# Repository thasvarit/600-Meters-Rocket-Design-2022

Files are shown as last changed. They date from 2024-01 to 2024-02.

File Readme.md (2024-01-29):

# Rocket Optimization Project Overview

## Introduction

The [Thailand CANSANT-ROCKET Competition](https://www.facebook.com/p/CanSat-Rocket-Thailand-100038803825229/), organized by the National Science Museum (NSM) and the Defence Technology Institute (DTI), invites high school students to design and test CanSats and rockets. For the rocket part, students don't have to create their own rocket motor, with the total impulse of 255 Ns, as DTI has it covered.

This GitHub page displays our rocket project for Team Nuage, the winner of the Aerodynamics Award at the Thailand CANSAT-ROCKET Competition 2022. Thanks to Phachara Phumiprathet's guidance, we've set a more realistic goal within our time constraints. My role is to design the rocket for our team in this competition.

## Method

I started using rocket optimization feature of [OpenRocket](https://openrocket.info/) to increase its altitude by tweaking the nose cone's shape and length. Strangely, OpenRocket suggested a short, blunt nose cone. I was skeptical, but when I double-checked with [Aerolab](https://www.nakka-rocketry.net/softw.html#Aerolab), the results matched. It seemed strange, going against [what we knew about physics](https://aerospaceweb.org/question/aerodynamics/q0151.shtml).

Digging deeper, I found pressure drag was a big factor. So, I went with a [von Kármán-style nose cone](https://en.wikipedia.org/wiki/Nose_cone_design#Von_K%C3%A1rm%C3%A1n) of with the length of 12 cm to lower pressure drag without adding the weight that comes with a longer nose cone.

Wisit Wipudgasamsook also recommended striking the right balance between static margin and altitude, so I get a 2 cm tip chord length, influencing the design of the fins. Adhering to the competition's requirement of 4 fins, my design decisions were not only in compliance but also geared towards ensuring the rocket's balance and optimal performance.

Following my design process, Shinakrit Laokittichai proceeded to assemble the rocket components in preparation for launch.

## Outcome

During the presentation before the launch, the committees weren't sure about the simulation results showing an altitude of 652 m. They thought it was too high since the given rocket motor from DTI was supposed to reach a maximum of 600 m. I double-checked everything in my simulations but found no issues.

In the end, my rocket reached 577 meters, slightly off from the expected result by 12%. Still, it outperformed other teams, whose rockets had an average altitude of 391 meters with a standard deviation of 120. The result of all this work is that our rocket got the Best Aerodynamics Award from the Thailand CANSAT-ROCKET Competition 2022.

## Citation

[1] Thitasirivit, Vivatsathorn & Ngamdeevilaisak, Bhavat & Vongbunsin, Chayakorn. (2018). Agricultural Exploration Assistant Satellite: Thailand CanSat Competition 2018 Preliminary Proposal. DOI: [10.13140/RG.2.2.11933.38882](https://doi.org/10.13140/RG.2.2.11933.38882)

[2] M. Ostaszewski, K. Dzierzek, Ł. Magnuszewski (2018). "Analysis of data collected during CanSat mission." In 2018 19th International Carpathian Control Conference (ICCC), Szilvasvarad, Hungary, pp. 1-4. DOI: [10.1109/CarpathianCC.2018.8399591](https://doi.org/10.1109/CarpathianCC.2018.8399591)

[3] Abate, M. T., Anandapadmanaban, E., Bao, L., Challani, S., Gaughan, J., Jiang, A., ... Zorn, S. E. (2014). Correlation between simulated, calculated, and measured model rocket flight. Retrieved from https://www.semanticscholar.org/paper/CORRELATION-BETWEEN-SIMULATED-%2C-CALCULATED-%2C-AND-Abate-Anandapadmanaban/f1273cf8d5df09aa30bc7d80c9ef3b260b1a4f53

[4] Crowell, G. A. (n.d.). The Descriptive Geometry of Nose Cone. Retrieved from https://www.scribd.com/doc/60921375/the-descriptive-geometry-of-nosecone

The images provided were captured by Vivatsathorn Thitasirivit, Nattakit Kwankitpisarn, Thanyapisit Kangsathien, Arkkanirut Pandej, and were sourced from a Facebook post by Dr. Rattapol Sakornsin.

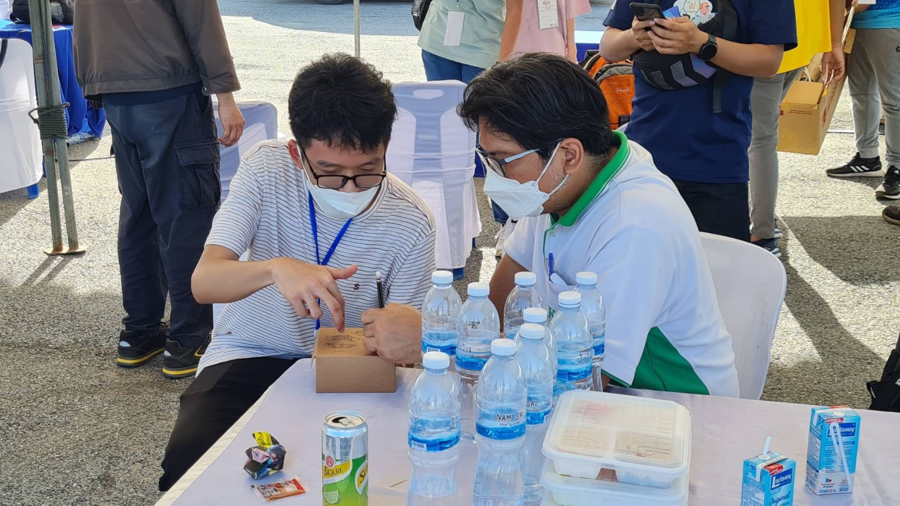
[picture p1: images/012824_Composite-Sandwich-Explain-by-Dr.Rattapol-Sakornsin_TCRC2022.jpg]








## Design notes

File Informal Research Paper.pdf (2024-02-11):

การออกแบบจรวดให้พิสัยการยิงมากที่สุดในช่วงความเร ็

วต่า กว่าเสียง ส าหรับ
รายการแข่งขัน Thailand CANSAT-ROCKET Competition 2022 ธรรศวริทธิ์เครือคลา้ย
ก

, ชินกฤต เหล่ากิตติชัยก

, วิศิษฎ์ วิพัฒน์เกษมสุขข

, พชร ภูมิประเทศก

ก

โรงเรียนอัสสัมชัญ
ขสถาบันเทคโนโลยีป้องกันประเทศ

ที่มาและความสำคัญ
ปัจจุบันการพัฒนาด้านวิศวกรรมการบิน และอวกาศของประเทศไทยยังคงอยู่ในช่วงเริ่มต้น โดยการยิง จรวดเพื่อการวิจัยทดสอบก่อนนำระบบไปใช้จริงนั้นเป็นหนึ่งในขั้นตอนสำคัญในการทำงาน ด้วยเหตุนี้จึงมีการ จัดการแข่งขัน Thailand CANSAT-ROCKET Competition 2022 ซึ่งเปิดโอกาสให้นักเรียนระดับมัธยมปลายได้ ออกแบบดาวเทียมจำลอง และจรวดเป็นของตนเอง โดยได้รับการสนับสนุนจากกระทรวงวิทยาศาสตร์ และ เทคโนโลยีแห่งชาติ (สวทช.) และสถาบันเทคโนโลยีป้องกันประเทศ (สทป.) การศึกษานี้จะศึกษาปัจจัยที่ส่งผลต่อ การออกแบบจรวดให้ลู่ลม เพื่อพิสัยการยิงสูงสุดของจรวด ภายใต้ข้อจำกัดของการแข่งขัน ข้อจำกัดในการออกแบบจรวด
รายการแข่งขัน Thailand CANSAT TOCKET Competition 2022 กำหนดให้ใช้ท่อจรวดที่มีเส้นผ่าน ศูนย์กลางนอก 80 mm โดยมีความหนา 2 mm และใช้มอเตอร์จรวดที่มีการดลรวม 255 mS ในการขับเคลื่อน

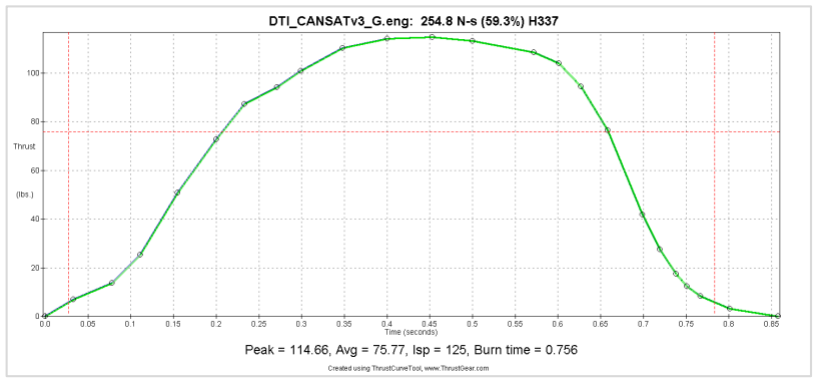
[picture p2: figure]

ภาพที่ 1: กราฟแรงขับของมอเตอร์จรวดจากโปรแกรม Thrust Curve Tool

ระเบียบวิธีการวิจัย

### 1. การออกแบบหัวจรวด ทำการทดลองทดสอบอิทธิพลจากการใช้หัวจรวดทุกประเภทที่สามารถ Simulation

ผ่านโปรแกรม OpenRocket ซึ่งได้แก่ LV-Haack, LD-Haack, 0.5 Parabola, 0.75 Parabola, Ellipsoid. Conical. Tangent Ogive และ Secant Ogive ที่ความยาวตั้งแต่ 1 – 30 cm ซึ่งรวมถึงช่วงความยาวใน อัตราส่วน 2 – 3 เท่าซึ่งเป็นช่วงที่เหมาะสมตามทฤษฎีการออกแบบหัวจรวด เมื่อเปรียบเทียบกับเส้นผ่าน ศูนย์กลางนอกของท้อจรวด โดยค่าที่พล็อตร่วมกับความยาวหัวจรวด คือข้อมูล Nose Cone Pressure Drag, Nose Cone Friction Drag และ Body Friction Drag ซึ่งนำเข้าข้อมูลจากแท็บ Drag Characteristic ของ หน้าต่าง Component Analysis จากโปรแกรม OpenRocket มาพล็อตเพื่อวิเคราะห์ในโปรแกรม Minitab

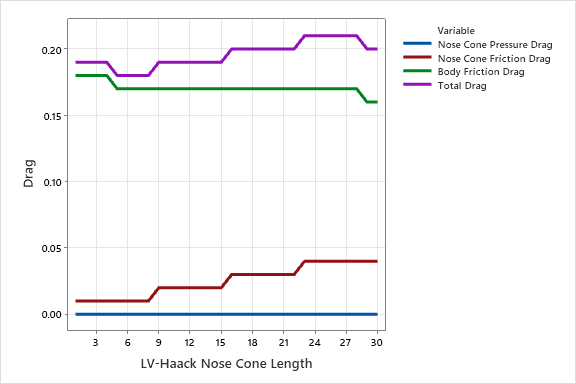
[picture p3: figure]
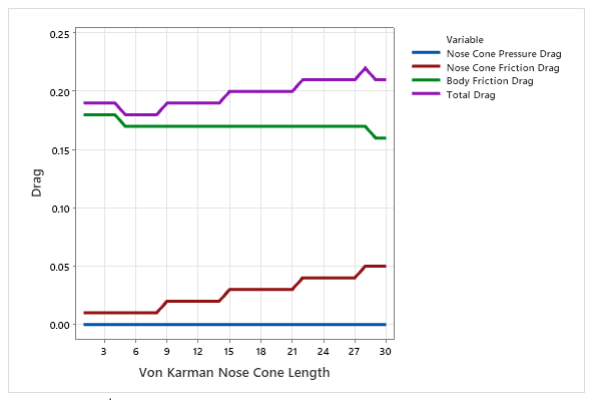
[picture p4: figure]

กราฟที่ 1: ความยาวหัวจรวด LV-Haack – แรงฉุด | กราฟที่ 2: ความยาวหัวจรวด Von Karman (LD-Haack) – แรงฉุด

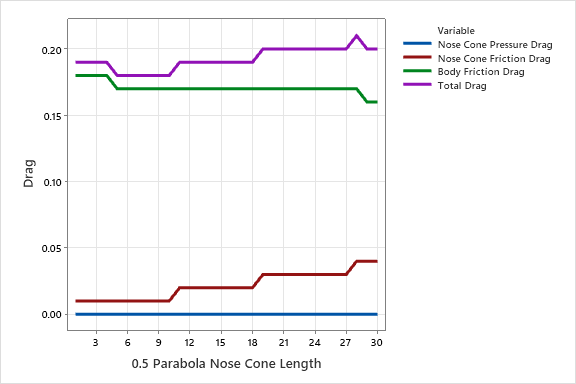
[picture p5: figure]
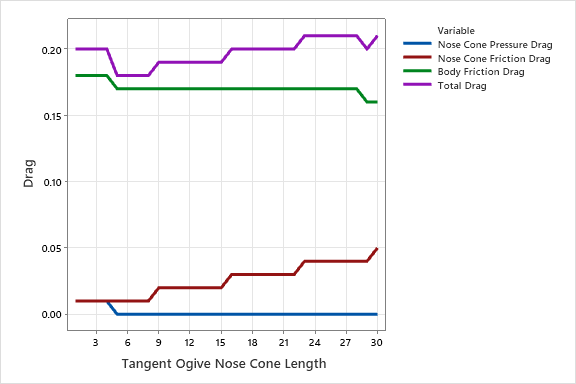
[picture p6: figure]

กราฟที่ 3: ความยาวหัวจรวด 0.5 Parabola – แรงฉุด | กราฟที่ 4: ความยาวหัวจรวด Tangent Ogive – แรงฉุด

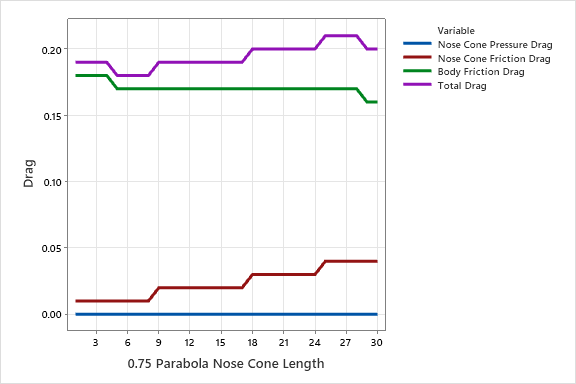
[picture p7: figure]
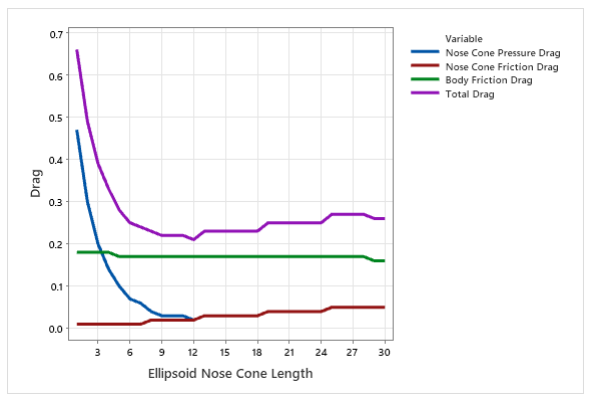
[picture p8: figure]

กราฟที่ 5: ความยาวหัวจรวด 0.75 Parabola – แรงฉุด | กราฟที่ 6: ความยาวหัวจรวด Ellipsoid – แรงฉุด

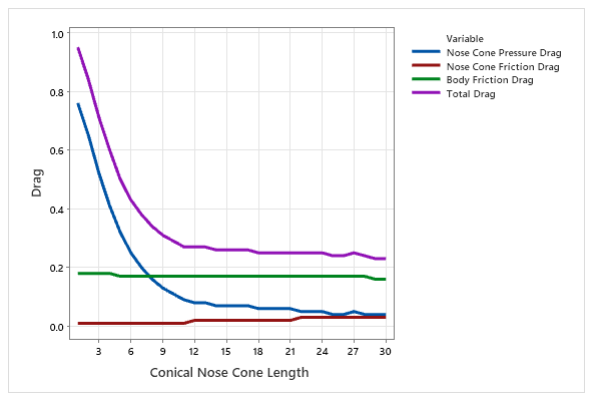
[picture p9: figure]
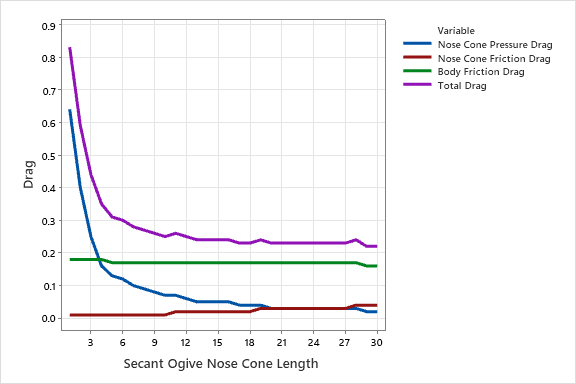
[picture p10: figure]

จะเห็นได้ว่าลักษณะของกราฟนั้นแบ่งออกเป็น 2 ประเภท ประเภทแรกคือกราฟที่มี แรงฉุดจากความดันต่อหัว จรวด (Nose Cone Pressure Drag) ใกล้เคียงกับ 0 คือกราฟที่ 1 – 5 ซึ่งได้แก่หัวจรวดทรง Von Karman, LV-Haack, 0.5 Parabola, Tangent Ogive และ 0.75 Parabola และประเภทที่ 2 คือกราฟที่ 6 – 8 คือประเภทที่มี แรงฉุดจากความดันต่อหัวจรวดต่ำลงตามความยาวของหัวจรวด ซึ่งตามทฤษฎีทางอากาศพลศาสตร์ แนวโน้มของ แรงฉุดความดันต่อหัวจรวดควรเป็นเหมือนกราฟประเภทที่ 2 คือแรงฉุดจากความดันจะมีค่ามากเมื่อหัวจรวดมี ลักษณะทู่ และต่ำลงเมื่อหัวมีลักษณะแหลมมากขึ้น ดังนั้นผู้ศึกษาจึงตั้งสมมติฐานเพื่อเลือกความยาวที่เหมาะสม ของหัวจรวดว่าแท้จริงแล้วแรงฉุดจากความดันของกราฟประเภทแรก ย่อมต้องเป็นไปในทิศทางเดียวกับกราฟ ประเภทที่ 2 และโดยภาพรวม ตัวแปรที่มีความผันแปรมากที่สุดตามความยาวของหัวจรวด คือแรงฉุดจากความดัน ต่อหัวจรวด โดยจากกราฟ อัตราการลดลงของแรงฉุดจากความดันต่อหัวจรวดจะลดลงเมื่อมีหัวจรวดมีความยาว มากขึ้น ความสูงของจรวดนั้นขึ้นอยู่กับ 2 ปัจจัยหลัก คือมวลของจรวด และแรงฉุดรวมต่อจรวด ซึ่งความยาวของ หัวจรวดส่งผลต่อทั้ง2 ปัจจัย ผู้ศึกษาจึงต้องหาจุดสมดุลระหว่างอิทธิพลของทั้ง 2 ปัจจัยเพื่อเลือกความยาวหัวจรวด ที่มีความเหมาะสมที่สุด แต่ด้วยข้อจำกัดด้านเวลา ผู้ศึกษาเลือกใช้หัวจรวดความยาว 12 เซนติเมตร ซึ่งเป็นความ ยาวที่ผู้ศึกษาเห็นว่าหลังจากพ้นค่านี้ไปแล้ว การเพิ่มความยาวของหัวจรวดจะลดปริมาณแรงฉุดเพียงเล็กน้อย สำหรับการคัดเลือกรูปร่างหัวจรวด ผู้ศึกษาใช้การคัดเลือกจากการทบทวนวรรณกรรม และใช้หัวจรวดทรง Von Karman ซึ่งเป็นทรงหัวจรวดที่ถูกออกแบบขึ้นมาเพื่อลดแรงฉุดโดยเฉพาะ โดยสมการเพื่อกำหนดรูปร่างของหัว จรวดทรง Von Karman คือ

y =

1
√π

√θ −
1
2

sin (2θ)

เมื่อ θ = cos⁻¹
(1 – 2x )

สมการที่ 1: เส้นโค้ง Von Karman

กราฟที่ 7: ความยาวหัวจรวด Conical – แรงฉุด | กราฟที่ 8: ความยาวหัวจรวด Secant Ogive – แรงฉุด

จึงนำสมการดังกล่าวไปเขียนโปรแกรมในโปรแกรม Matlab ดังภาพที่ 9 โดยกำหนดให้เส้นผ่านศูนย์กลางของหัว จรวดเท่ากับ 80 และความยาวหัวจรวดเท่ากับ 120 ซึ่งจากการเพิ่มค่าความยาวหัวจรวดในลูปของโปรแกรมแต่ละ ครั้ง ครั้งละ 0.1 ทำให้ได้พิกัดเพื่อสร้างเส้นโค้ง Von Karman ทั้งหมด 1200 พิกัด โดยได้ทำการพล็อตทดสอบดัง ภาพที่ 10 จากนั้นนำเข้าพิกัดเข้าสู้โปรแกรม SolidWorks ทำการ Offset 2 เซนติเมตร แล้ว Revolve รอบแกนให้ หัวจรวด Von Karman มีความหนา 2 เซนติเมตร จากนั้นสร้าง Shoulder โดยกำหนดให้มีเส้นผ่านศูนย์กลางนอก เล็กกว่าท่อจรวด 0.5 เซนติเมตร และมีความยาว 5 เซนติเมตร เพื่อให้สามารถเสียบหัวจรวดเข้ากับท่อจรวดได้พอดี

2.การออกแบบครีบจรวด เนื่องจากผู้ศึกษามีความสนใจในการออกแบบครีบจรวดแบบสี่เหลี่ยมคางหมู การศึกษา นี้จึงมุ่งศึกษาปัจจัยที่ส่งผลต่อความสูงของครีบจรวดแบบสี่เหลี่ยมคางหมูซึ่งตัวแปรที่สำคัญที่สุดในการออกแบบ ครีบแบบสี่เหลี่ยมคางหมู คือความยาวคอร์ดปลายครีบ โดยความยาวคอร์ดปลายครีบจะส่งผลต่อสมดุล และความ สูงการยิงของจรวดในการจำลอง ซึ่งการเลือกความยาวคอร์ดปลายครีบที่เหมาะสมที่สุด ควรเลือกจากจุดสมดุล ระหว่างความสูงการยิง และความสมดุล ซึ่งสามารถคำนวณได้จากสมการที่ 2 ซึ่งจากกราฟที่ 4 จะเห็นได้ว่าจุดสม ดลอยู่ทึ่ความยาวคอร์ดปลายครีบราว 1.8 cm แต่เพื่อความสะดวกในการผลิต ครีบจรวดจริงจึงใช้ความยาวคอร์ด ปลายครีบ 2 cm ซึ่งเป็นจำนวนเต็มที่อยู่ใกล้ 1.8 cm มากที่สุด

Static Margin =

CP − CG
เส้นผ่านศูนย์กลางนอกท่อจรวด

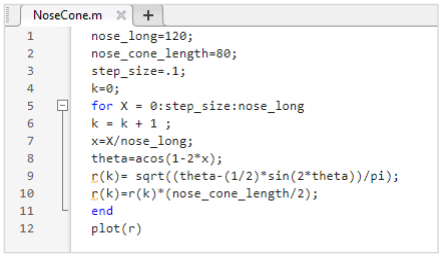
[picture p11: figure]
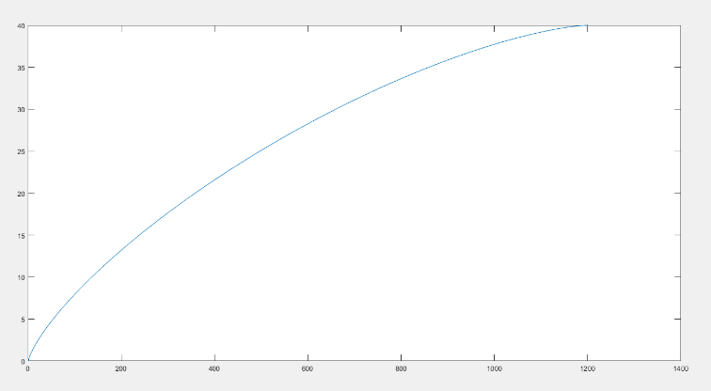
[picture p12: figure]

ภาพที่ 2: โค้ด Matlab สำหรับพล็อตเส้นโค้ง Von Karman | ภาพที่ 3: เส้นโค้ง Von Karman

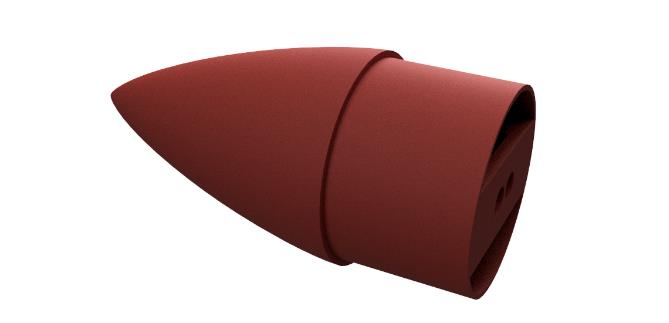
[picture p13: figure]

ภาพ 4: หัวจรวด Von Karman ของ NuageRocket

สมการที่ 2: Static Margin

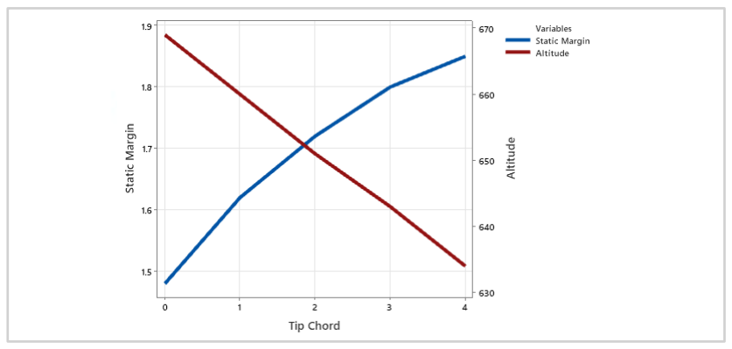
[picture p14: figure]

กราฟที่ 9: จุดสมดุลของความสมดุล และความสูงการยิง

3.ผลจากการจำลองจากการจำลองในโปรแกรม OpenRocket การใช้หัวจรวด Von Karman ที่ความยาว 12 cm และครีบจรวดแบบสี่เหลี่ยมคางหมูที่มีความยาวคอร์ดปลายครีบ 2 cm จะทำให้จรวดยิงขึ้นไปเป็นความสูง สูงสุดที่ 652 m ดังแสดงในกราฟที่ 10

การทดสอบจรวด

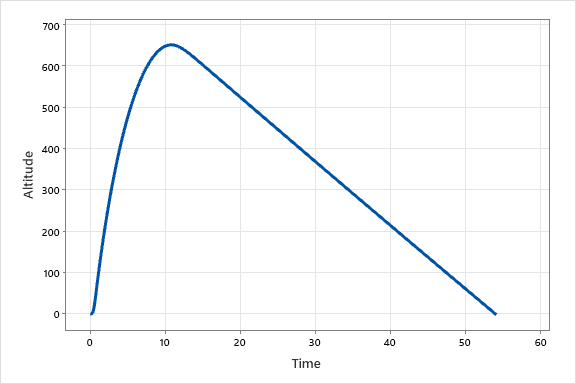
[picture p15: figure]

ในการแข่งขันจริง จากการสังเกตลักษณะ CanSat ของทีมที่ทำการยิงจรวดก่อนหน้า พบว่ามีหลายทีมที่ไฟ จาก Delay Charge ลามขึ้นไปเผา CanSat, ร่มชูชีพ และส่วนประกอบอื่น ๆ ที่ผู้เข้าแข่งขันใส่ไวในจรวด ซึ่งการวาง CanSat แบบเดิมอาจทำให้ร่มชูชีพถูกเผาไหม้ จึงเปลี่ยนทิศทางการวางของร่มชูชีพให้อยู่ห่างจาก Delay Charge มากขึ้นเพื่อตัดปัญหา โดยการสลับตำแหน่งดังกล่าวทำให้ค่า Static Margin เพิ่มขึ้นจาก 1.62 Calibers เป็น 1.73 Calibers ซึ่งยังอยู่ในช่วง 1 – 2 คือเป็นจรวดที่มีความสมดุลอยู่ นอกจากนี้ได้พันผ้าสักหลากที่ลูกสูบเพื่อกันไม่ให้ไฟ ลามขึ้นไปเผาส่วนประกอบอื่น ๆ และจากการยิงจรวด ความสูงการยิงของจรวดของผู้ศึกษาจรวดเป็นกลุ่มที่ยิงขึ้น ไปได้สูงที่สุดที่ 577 m ซึ่งน้อยกว่าที่จำลองไว้แต่มากกว่าค่าเฉลียเลขคณิตของทุกทีมคือ 390.8 m ที่ 186.2 m อย่างไรก็ตาม การจำลองจรวดเพื่อเลือกความยาวที่เหมาะสมของหัวจรวดของการศึกษานี้ตั้งอยู่บนสมมติฐานว่า แรงฉุดจากความดันต่อหัวจรวดของกราฟประเภทที่ 1 น่าจะมีค่าใกล้เคียงกับค่าในกราฟประเภทที่ 2 โดยเป็น สมมติฐานที่ยังไม่ถูกทดสอบ ซึ่งการคำนวณตามทฤษฎีที่โปรแกรม OpenRocket ใช้งานจะต้องถูกตรวจสอบต่อไป

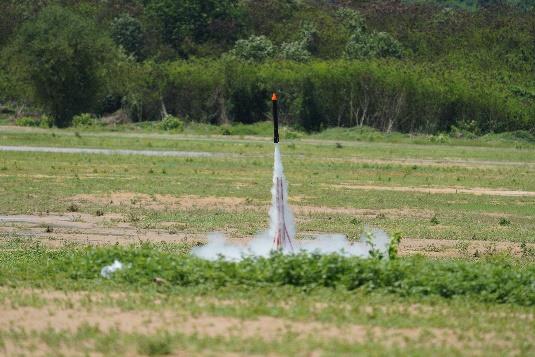
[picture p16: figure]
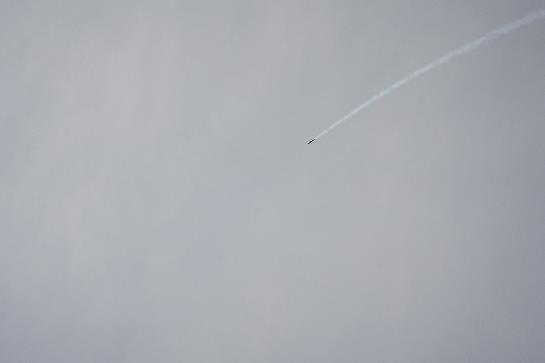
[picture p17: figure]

ภาพ 5: จรวดถูกยิงออกจากแท่น | ภาพ 6: จรวดขณะอยู่กลางท้องฟ้า

กราฟที่ 10: กราฟความสูงการยิงจรวดตลอดการทำงาน

บรรณานุกรม
Thitasirivit, Vivatsathorn & Ngamdeevilaisak, Bhavat & Vongbunsin, Chayakorn. (2018). Agricultural Exploration Assistant Satellite: Thailand CanSat Competition 2018 Preliminary Proposal.
DOI: 10.13140/RG.2.2.11933.38882 (https://doi.org/10.13140/RG.2.2.11933.38882)
M. Ostaszewski, K. Dzierzek, Ł. Magnuszewski (2018). "Analysis of data collected during CanSat mission." In 2018 19th International Carpathian Control Conference (ICCC), Szilvasvarad, Hungary, pp. 1-4. DOI: 10.1109/CarpathianCC.2018.8399591 (https://doi.org/10.1109/CarpathianCC.2018.8399591)

Abate, M. T., Anandapadmanaban, E., Bao, L., Challani, S., Gaughan, J., Jiang, A., ... Zorn, S. E. (2014). Correlation between simulated, calculated, and measured model rocket flight. Retrieved from https://www.semanticscholar.org/paper/CORRELATION-BETWEEN-SIMULATED-%2C-CALCULATED-%2C-AND-Abate-Anandapadmanaban/f1273cf8d5df09aa30bc7d80c9ef3b260b1a4f53 (https://www.semanticscholar.org/paper/CORRELATION-BETWEEN-SIMULATED-%2C-CALCULATED-%2C-AND-Abate-Anandapadmanaban/f1273cf8d5df09aa30bc7d80c9ef3b260b1a4f53)
Crowell, G. A. (n.d.). The Descriptive Geometry of Nose Cone. Retrieved
from https://www.scribd.com/doc/60921375/the-descriptive-geometry-of-nosecone

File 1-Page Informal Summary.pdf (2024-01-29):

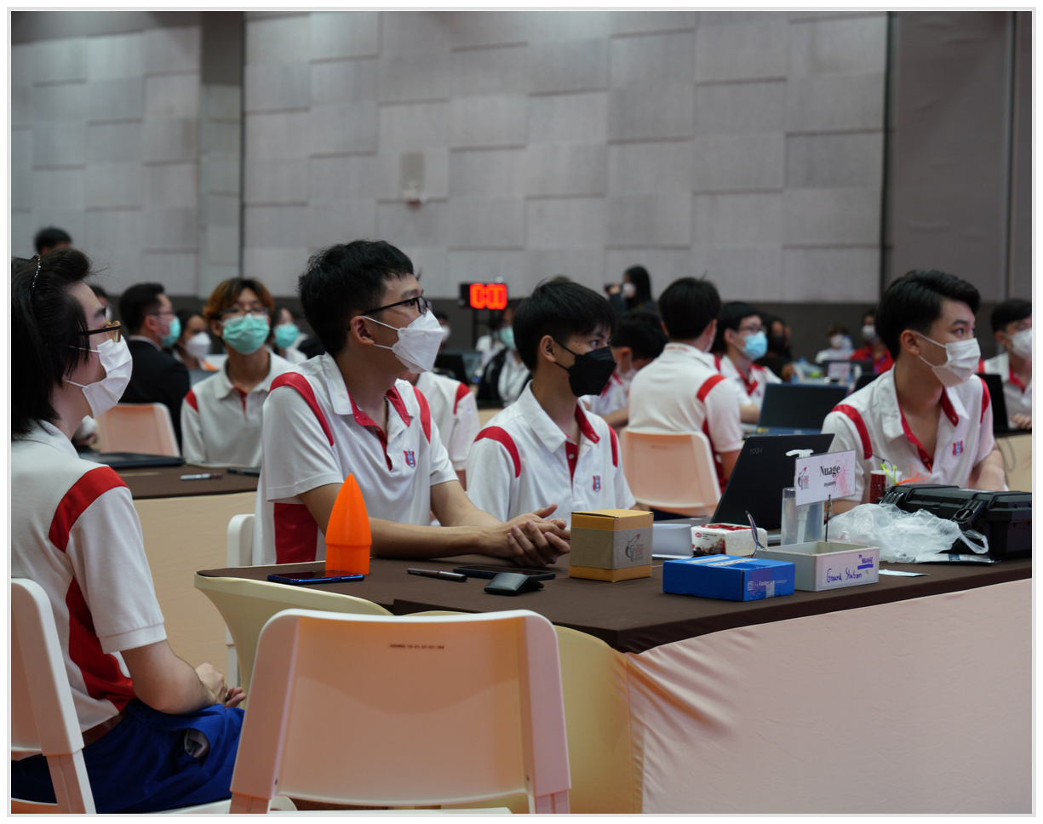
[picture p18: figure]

Our investigation commences with a thorough analysis of various rocket head shapes and their impact on aerodynamic performance. Using the OpenRocket program, simulations were conducted for shapes such as Von Karman, LV-Haack, 0.5 Parabola, 0.75 Parabola, Ellipsoid, Conical, Tangent Ogive, and Secant Ogive. Detailed analysis of drag forces, covering Nose Cone Pressure Drag, Nose Cone Friction Drag, and Body Friction Drag, revealed distinct graph patterns. Recognizing limitations in accurately simulating the Von Karman curve, we made informed assumptions based on observed drag behavior in other nose cone shapes, leading to the selection of a 12-centimeter Von Karman rocket head. Continuing our exploration, we delved into the factors influencing the height of trapezoidal rocket fins. Prioritizing trapezoidal fin design, OpenRocket simulations were employed to optimize the fin tip chord length, ensuring a delicate balance between altitude and rocket stability. The final decision led to a 2-centimeter chord length at the fin tip, a critical variable in achieving overall rocket performance.

# Optimizing Rocket Design for Maximum Altitude in Thailand CANSAT - ROCKET Competition 2022

The aeronautical and space engineering landscape in Thailand is still in its early stages, with ongoing efforts to cultivate interest and expertise in the field. The Thailand CANSAT – ROCKET Competition 2022, organized by the National Science Museum (NSM) and the Defence Technology Institute (DTI), , offers a unique opportunity for high school students to explore aerospace engineering. This research is centered on the design optimization of rocket components, specifically the rocket nose cone and fins, to improve performance and maximize altitude in the competition. This project is supported by SPACE AC Institute of Technology.

During the presentation phase, skepticism arose regarding simulation results indicating an altitude of 652 m, surpassing the expected maximum of 600 m. Double-checking revealed no simulation issues. In the launch, the rocket achieved 577 m, slightly deviating from the simulation but securing the highest altitude. Despite this discrepancy, our efforts culminated in the rocket receiving the esteemed Best Aerodynamics Award at the Thailand CANSAT – ROCKET Competition 2022

# INTRO

# METHOD

# OUTCOME

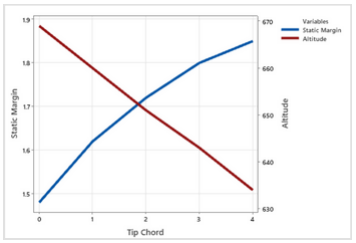
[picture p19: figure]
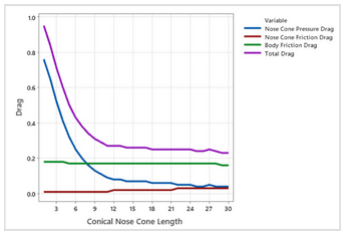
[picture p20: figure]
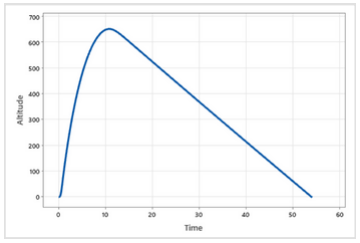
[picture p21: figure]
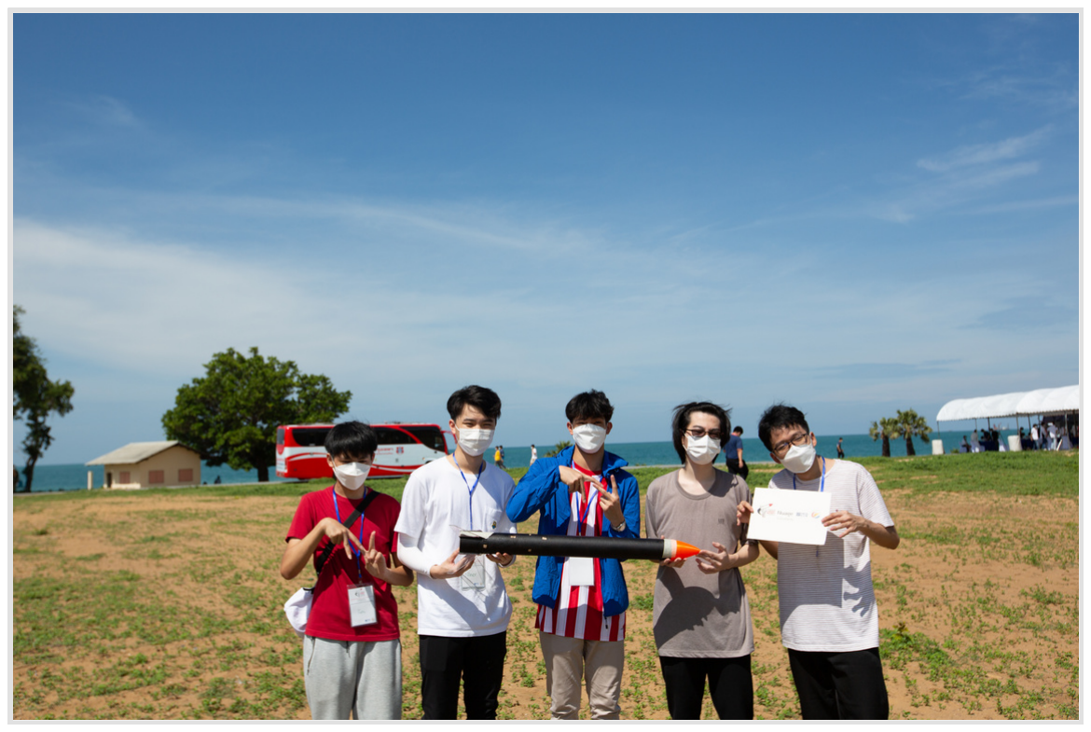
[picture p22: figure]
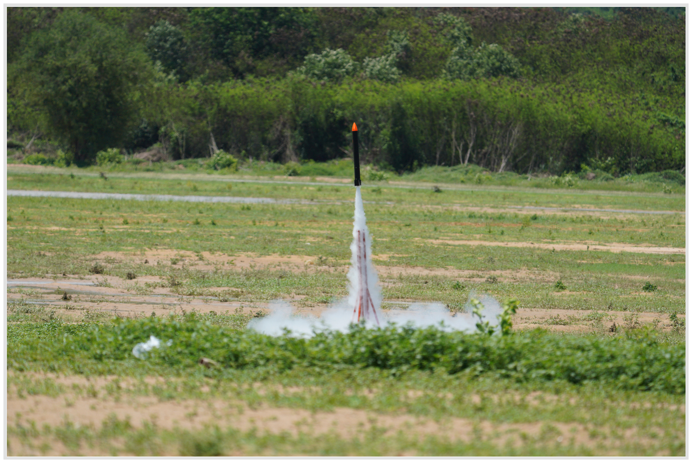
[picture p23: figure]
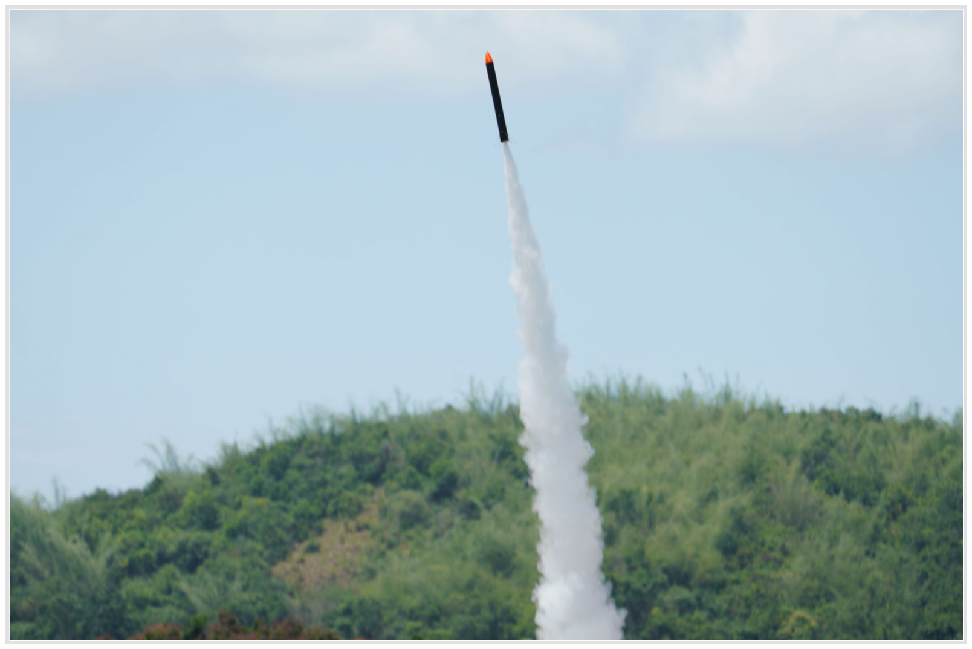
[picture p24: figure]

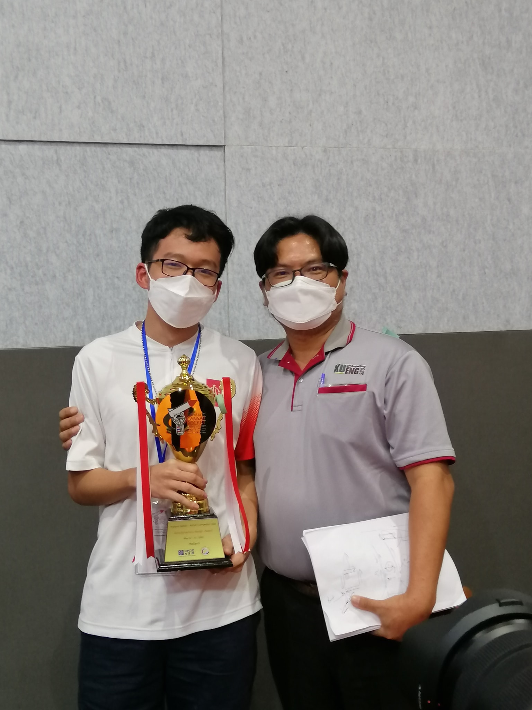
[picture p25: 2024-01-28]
images/012824_Trophy-with-Dr.Rattapol-Sakornsin.jpg

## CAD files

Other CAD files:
Nose Cone CAD Model.f3d
